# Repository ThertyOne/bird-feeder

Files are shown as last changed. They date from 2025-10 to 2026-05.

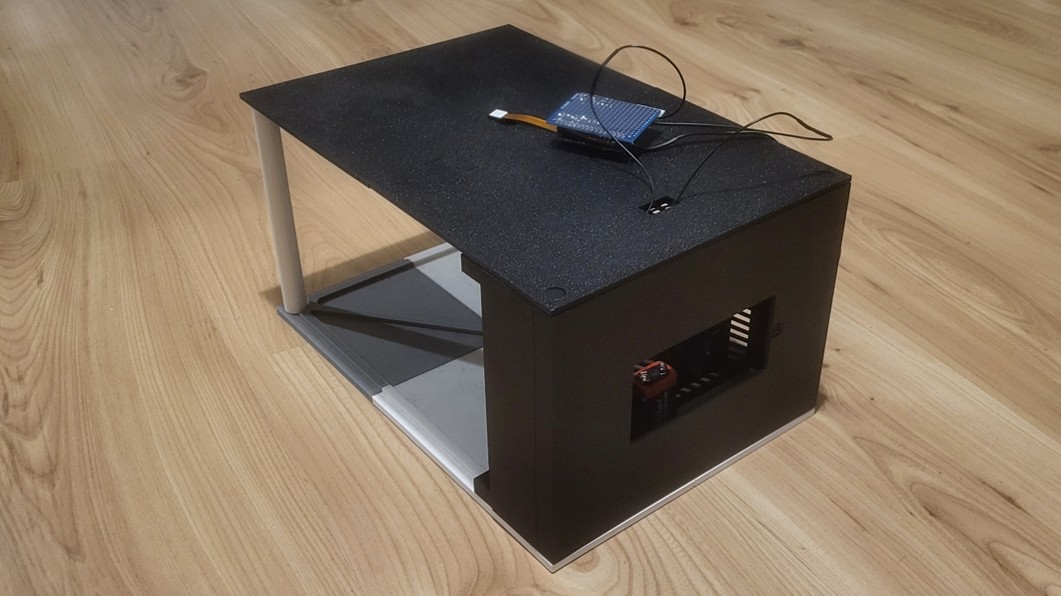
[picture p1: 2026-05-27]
SPRAWOZDANIE/Zdjęcie.jpg

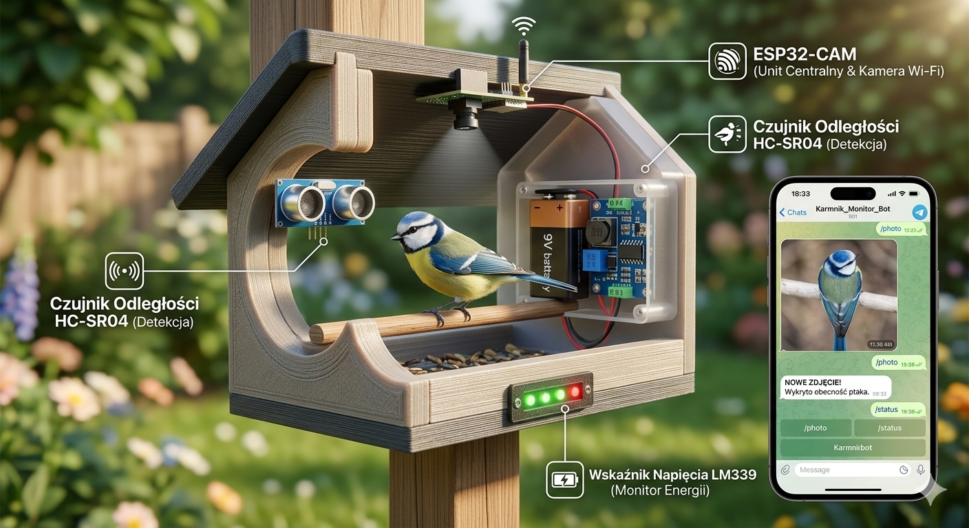
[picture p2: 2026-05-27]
SPRAWOZDANIE/wizualizacja.png

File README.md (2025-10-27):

# 🐦 Solar Bird Feeder

## 📘 Opis projektu
Projekt to **autonomiczny karmnik dla ptaków z funkcją wykonywania zdjęć**, oparty na module **ESP32-CAM**, zasilany z akumulatora **Li-Po 3,7 V / 2200 mAh**, ładowanego przez ładowarkę **TP4056** z panelem solarnym **6 V / 1 W** (możliwość połączenia 2 paneli szeregowo).  

Z wyjścia baterii energia trafia do **przetwornicy boost 5 V**, zbudowanej od podstaw na bazie generatora **PWM LMC555** i MOSFETa **IRLML6344**, która zasila ESP32 i peryferia – **serwo sterujące karmnikiem, LEDy oświetleniowe oraz czujniki**. Masa wszystkich modułów jest wspólna.  

Ładowanie z panelu odbywa się przez **diodę SS34** i **polyfuse 500 mA**, a napięcie akumulatora jest monitorowane przez dzielnik rezystorowy podłączony do ADC ESP.  

Po wykryciu ruchu przez czujnik ESP wychodzi z trybu **deep sleep**, włącza LED, wykonuje zdjęcie i wysyła je przez Wi-Fi na serwer, po czym ponownie przechodzi w uśpienie, oszczędzając energię. **Peryferia** (serwo, LEDy) są zasilane poprzez **klucz MOSFET**, który odcina zasilanie, gdy peryferia nie działają.

---

## ⚙️ Główne założenia
- Zasilanie autonomiczne: **panel solarny + akumulator Li-Po 3.7 V / 2200 mAh**
- Mikrokontroler i kamera: **ESP32-CAM (OV2640)**
- Komunikacja: **Wi-Fi**, opcjonalnie **LoRaWAN** w przyszłości
- Peryferia:
  - **Ultradźwiękowy czujnik / PIR** – detekcja obecności ptaka
  - **Serwo** – mechanizm podawania karmy
  - **Blue LED matrix 4x4** – doświetlenie sceny podczas zdjęcia
- ESP32 w trybie **deep sleep**, wybudzanie po przerwaniu z czujnika
- Przesyłanie zdjęcia i metadanych (data, godzina) do serwera lub lokalnej bazy danych

---

## ⚡ Przetwornica boost 5 V
- Źródło PWM: **LMC555 @ ~100 kHz, 3.3 V**
- MOSFET: **IRLML2502 / IRLML6344**
- Cewka: **15 μH**
- Dioda: **SS34**
- Kondensator wyjściowy: **4700 μF**
- Ograniczenie napięcia: **Zener 5 V**
- Funkcja: podnosi napięcie z 3,7 V akumulatora Li-Po do stabilnych 5 V dla ESP32 i peryferiów

---

## 🔋 Szacowane zużycie prądu
| Moduł | Tryb/obciążenie | Prąd (mA) |
|---|---|---|
| ESP32-CAM | Deep sleep | 0.1 – 0.2 |
| ESP32-CAM | Aktywne (Wi-Fi + foto) | 180 – 250 |
| Serwo | Ruch | 150 – 200 |
| LEDy | Max 4 LED | 80 – 100 |
| Czujniki | Idle | 2 – 5 |

**Średni pobór prądu:** ~10–30 mA przy większości czasu w deep sleep.  
**Maksymalny chwilowy pobór:** ~500 mA przy jednoczesnym ruchu serwa i LED.

---

## 💡 Sposoby oszczędzania energii
- ESP32 w **deep sleep**, wybudzenie tylko przy wykryciu ruchu
- Peryferia (LED, serwo) zasilane przez **MOSFET**, odcięcie zasilania gdy nieaktywne
- Minimalizacja czasu pracy Wi-Fi i kamer
- Możliwość zmniejszenia jasności LED i liczby LED w pierścieniu
- Optymalizacja częstotliwości wybudzeń w zależności od natężenia odwiedzin ptaków

---

## ☀️ Energia z baterii i paneli
- **Akumulator Li-Po:** 3,7 V / 2200 mAh → **8,14 Wh**
- **Panel solarny:** 6 V / 1 W → maksymalny prąd ładowania ~167 mA (przy pełnym słońcu)
- **2 panele szeregowo:** napięcie 12 V / prąd ~83 mA, dalej prostownik i TP4056
- **Przetwornica boost 5 V:** sprawność ~85 % → prąd pobierany z akumulatora = Iout × 5 V / (η × 3,7 V)
- **Szacowany średni pobór prądu ESP32 + peryferia:** 50 mA @ 5 V  
  I_bat ≈ (5V * 0.05A) / (0.85 * 3.7V) ≈ 79,5 mA
- **Czas pracy na baterii bez słońca:**  
  Czas pracy na baterii ≈ 2200 mAh / 79,5 mA ≈ 27,7 h ≈ 1,15 dnia
- **Chwilowe piki prądu** (serwo + LED + Wi-Fi): ~500 mA @ 5 V → Ibat_peak ≈ 800 mA  
- **Przy słonecznej pogodzie** panele mogą praktycznie utrzymać akumulator w pełnym stanie, a nawet doładować go na zapas (np. 4–5 h słońca → ~4 Wh energii)

---

## 🔧 Uwagi do przetwornicy
- Układ **boost 5 V** przy chwilowych pikach prądu (serwo + LED + Wi-Fi) mogą wystąpić spadki napięcia
- Kondensator 4700 μF pomaga w wygładzaniu napięcia przy skokach prądowych
- Zener 5 V chroni ESP32 przed przepięciem, ale warto monitorować temperaturę MOSFETa i cewki przy pełnym obciążeniu
- Ewentualne zwiększenie cewki lub dodanie małego kondensatora ceramicznego przy MOSFET zwiększy stabilność przy dużym poborze

---

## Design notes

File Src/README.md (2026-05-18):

# Intelligent Bird Feeder ESP32-CAM

Oprogramowanie do projektu inteligentnego karmnika dla ptaków oparty o moduł ESP32-CAM.  
System łączy się z siecią Wi-Fi, komunikuje się z botem Telegrama i docelowo ma wykonywać zdjęcia oraz rozpoznany gatunek, po wykryciu obecności ptaka.

## Funkcjonalności

Aktualnie zaimplementowane:

- konfiguracja projektu przez osobny plik `config.h`,
- połączenie ESP32-CAM z siecią Wi-Fi,
- inicjalizacja kamery OV2640,
- wykonywanie zdjęcia,
- wysyłanie zdjęcia przez Telegram,
- podstawowa struktura modułowa kodu,
- detekcja ptaka z użyciem czujnika ruchu / odległości,
- obsługa komend Telegrama,
- przygotowany moduł komunikacji z Telegram Bot API.

Planowane / rozwijane:

- rozpoznawanie gatunku ptaka.

## Struktura projektu

```txt
src/
├── main.cpp
├── config.h                    # lokalny plik konfiguracyjny, nie obecny w repo
├── config.example.h            # przykładowa konfiguracja  
|     
├── sensors_n_actuators/        # moduły fizyczne
│     ├── camera/
│     |     ├── camera.h
│     |     └── camer.cpp
|     |
│     ├── pir_sensor/
│     |     ├── pir_sensor.h
│     |     └── pir_sensor.cpp
|     |
│     ├── wifi_meneger/
│           ├── wifi_meneger.h
│           └── wifi_meneger.cpp
|
└── telegram/                   # serwer Telegram
      ├── telegram.h
      └── telegram.cpp
```

## Konfiguracja
Utwórz plik `src/config.h` na podstawie `src/config.example.h`:
```c
#define SSID_1 "NAZWA_WIFI"
#define PASSWORD_1 "HASLO_WIFI"

#define BOT_TOKEN "TOKEN_BOTA_TELEGRAM"
#define CHAT_ID "ID_CZATU"

#define PIR_SENSOR_PIN 14
#define FLASH_LED_PIN 4
#define SERVO_PIN 15
```

## Uruchomienie debugowania
1. Skonfiguruj `config.h`.
2. Podłącz `ESP32-CAM` do stabilnego zasilania 5 V.
3. Wgraj program na płytkę.
4. Otwórz Serial Monitor z prędkością: `115200 baud`.
5. Sprawdź, czy urządzenie poprawnie łączy się z Wi-Fi.

## Docs
### Telegram:
Moduł `TelegramManager` odpowiada za komunikację ESP32-CAM z Telegram Bot API.

Obsługuje:
- wysyłanie wiadomości tekstowych,
- wysyłanie zdjęć JPEG,
- odbieranie prostych komend użytkownika.

## Wymagania konfiguracyjne

W pliku `config.h` muszą być zdefiniowane:

```cpp
#define BOT_TOKEN "telegram_bot_token"
#define CHAT_ID "authorized_chat_id"
#define BOT_REQUEST_DELAY 1000UL

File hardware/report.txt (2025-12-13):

Plotted to 'C:\Users\mrvan\OneDrive\Pulpit\plytka do roboty\hardware-B_Cu.gbr'.
Created Gerber job file 'C:\Users\mrvan\OneDrive\Pulpit\plytka do roboty\hardware-job.gbrjob'.
Informacja: Done.
Informacja: Done.

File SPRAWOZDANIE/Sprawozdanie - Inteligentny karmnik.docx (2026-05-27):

# Sprawozdanie projektowe

Inteligentny karmnik

Autorzy:

Dominik Bukowicz Jan Mikołajczyk Wojciech Odziomek Wojciech Kośnik-Kowalczuk | 268519 268563 264259 245728

# Cel pracy

Głównym celem projektu było zaprojektowanie i wykonanie autonomicznego systemu monitoringu ptaków, zintegrowanego z karmnikiem wykonanym w technologii druku 3D. Urządzenie ma za zadanie wykrywać obecność ptaków wewnątrz karmnika, wykonywać zdjęcie i przesyłać je w czasie rzeczywistym do użytkownika za pośrednictwem komunikatora Telegram.

# Założenia projektowe

Projekt opiera się na następujących założeniach technicznych:

- Jednostka centralna: Moduł ESP32-CAM z wbudowaną kamerą i łącznością Wi-Fi.
- Detekcja: Ultradźwiękowy czujnik odległości HC-SR04 wykrywający obiekt w zasięgu 2–200 cm.
- Zasilanie: Bateria 9V, obniżana do stabilnego poziomu 5V za pomocą przetwornicy impulsowej.
- Monitoring energii: Analogowy wskaźnik napięcia na komparatorze LM339, sygnalizujący poziom rozładowania baterii za pomocą 4 diod LED.
- Komunikacja: Telegram Bot API (interakcja przez Father Bot).
- Obudowa: Konstrukcja modułowa zaprojektowana do druku 3D.

# Uzasadnienie doboru elementów

Wybór komponentów podyktowany był optymalizacją kosztów oraz energooszczędnością:

- ESP32-CAM: Wybrany ze względu na zintegrowany moduł Wi-Fi oraz niską cenę w stosunku do możliwości przetwarzania obrazu.
- HC-SR04: Czujnik ten pozwala na precyzyjne określenie momentu pojawienia się ptaka przy ziarnie, co minimalizuje liczbę "pustych" zdjęć, w przypadku gdyby były one robione z określoną częstotliwością.
- Przetwornica LM2592 (Step-down): Zastosowanie przetwornicy impulsowej zamiast stabilizatora liniowego (np. 7805) pozwala na uzyskanie znacznie wyższej sprawności, co jest kluczowe przy zasilaniu bateryjnym.
- LM339: Poczwórny komparator napięcia pozwala na realizację czytelnego, 4-stopniowego wskaźnika poziomu energii przy minimalnej liczbie komponentów zewnętrznych.

# Symulacja układu elektronicznego w LtSpice

Przed przystąpieniem do projektowania płytki PCB, układ wskaźnika napięcia został poddany symulacji w programie LTSpice.

Analiza teoretyczna: Układ działa jako dzielnik napięcia porównujący napięcie baterii z napięciem odniesienia (5V z przetwornicy). Próg załączenia diody LED określa wzór:

V_(th) = V_(ref) (1+ (R_(pot_h) / R_(pot_l) ))

gdzie:

Vref - stałe napięcie 5V, a stosunek rezystancji potencjometru określa punkt krytyczny dla baterii 9V.

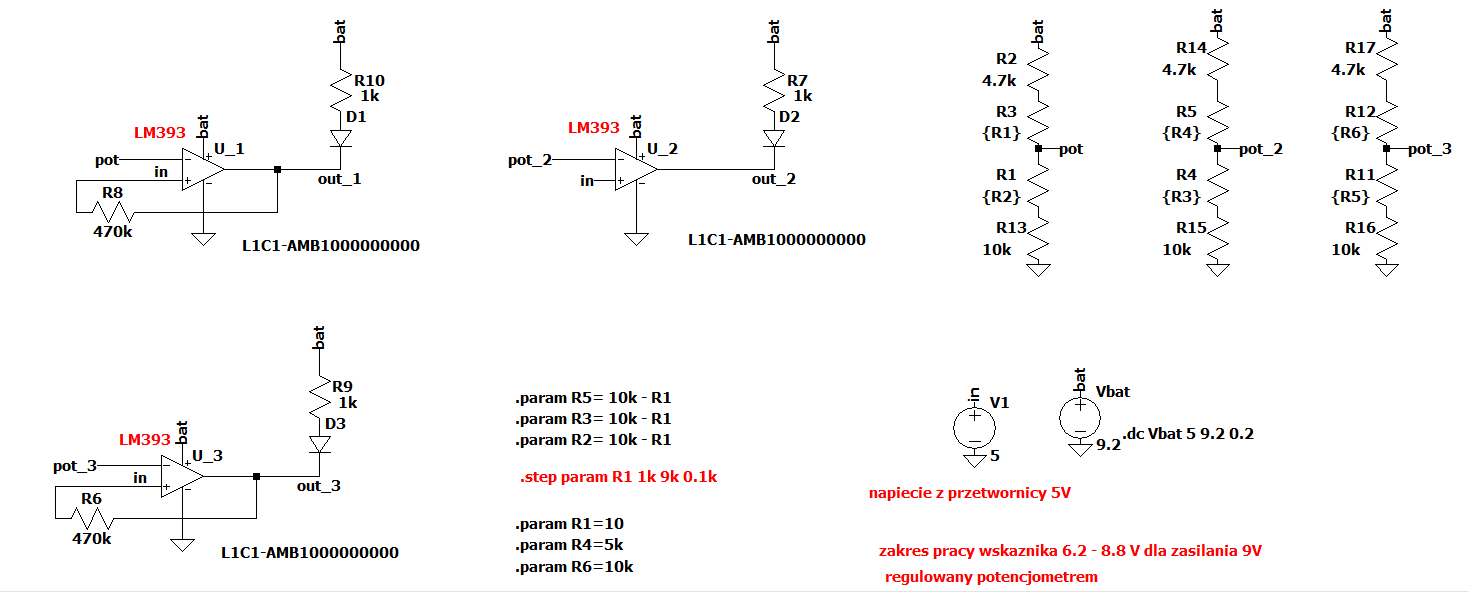
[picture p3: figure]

Rys. 1 Symulowany schemat

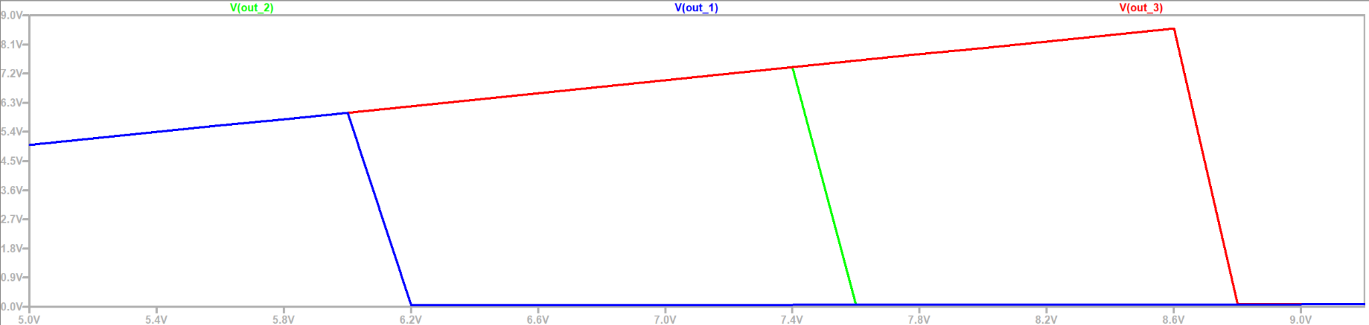
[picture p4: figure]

Rys. 2 Wynik symulacji

Symulacja wykazała, że układ poprawnie reaguje na spadek napięcia w zakresie od 8,8 V do około 6,2V, co odpowiada bezpiecznemu zakresowi pracy baterii alkalicznej.

# Projekt płytki obwodów drukowanych w KiCAD

Projekt PCB został zrealizowany w środowisku KiCAD. Zdecydowano się na płytkę jednostronną, co ułatwia jej wykonanie metodą termotransferu dostępnej w ramach laboratorium.

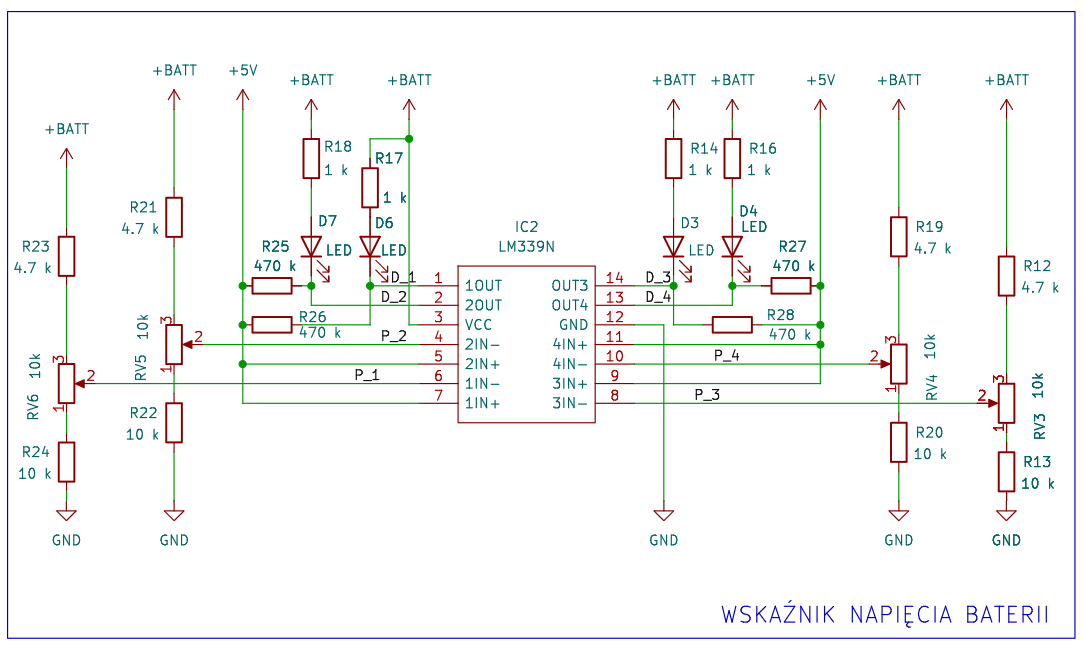
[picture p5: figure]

Rys. 3 Schemat elektryczny zaprojektowanego wskaźnika napięć

Cechy projektu PCB:

- Zasilanie: Płytka posiada dwa odseparowane wejścia: dla baterii 9V oraz dla napięcia 5V z modułu zewnętrznej przetwornicy.
- Prowadzenie ścieżek: Ze względu na ograniczenia jednej warstwy, zastosowano jedną "zworkę" (przelotkę przewlekany) dla szyny zasilania 5V.
- Kalibracja: Na płytce umieszczono cztery potencjometry montażowe (RV3-RV6), które pozwalają na precyzyjne ustawienie progów dla każdej z diod LED.

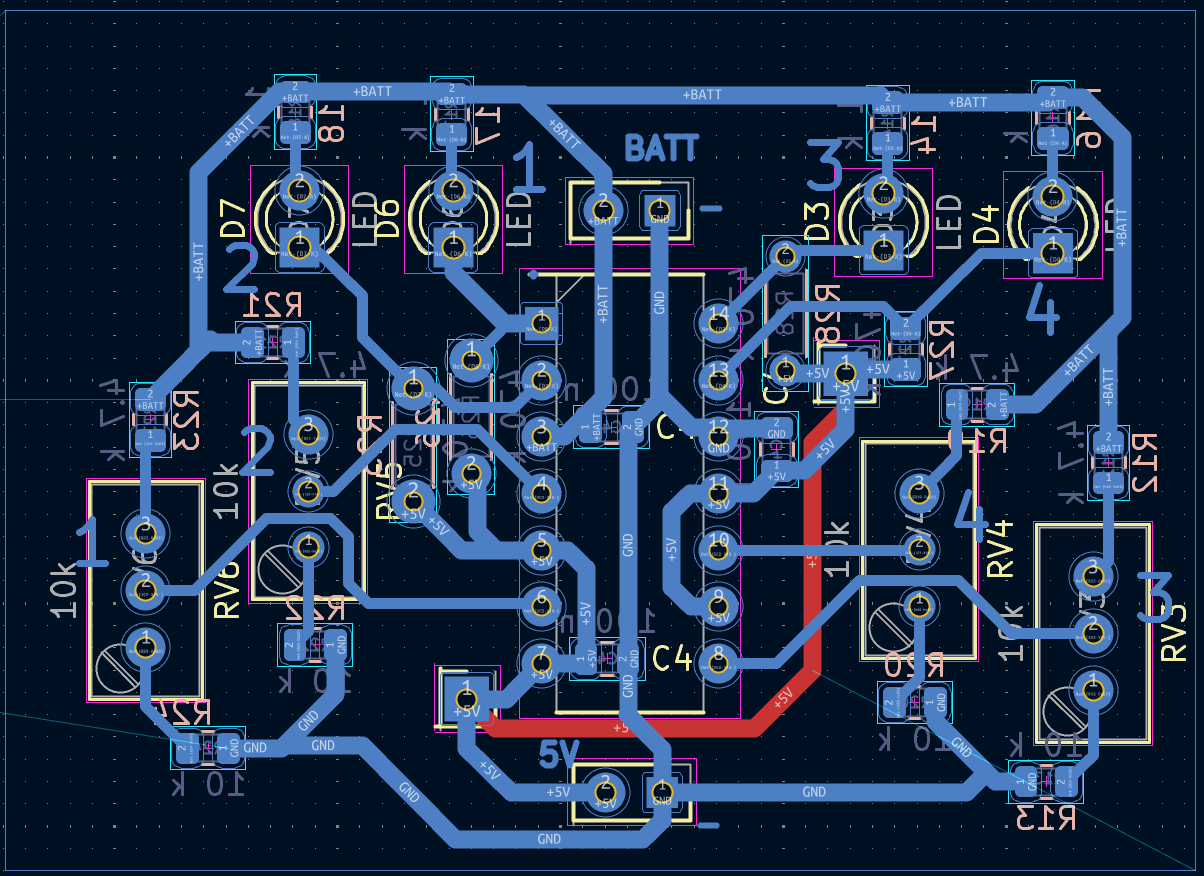
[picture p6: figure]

Rys. 4 Widok płytki jednostronnej

# Testy zaprojektowanego układu elektronicznego

Proces testowania skupił się na kalibracji wskaźnika napięcia oraz weryfikacji logiki ESP32-CAM.

1. Kalibracja wskaźnika: Do wejścia baterii podłączono zasilacz laboratoryjny. Zmieniając napięcie od 9.5V w dół, regulowano potencjometry tak, aby diody gasły kolejno przy poziomach: 8.5V, 7.8V, 7.0V oraz 6.5V. W celu uzyskania napięcia odniesienia Uref na czas testów wykorzystano pin 5V z ESP32.
2. Weryfikacja zasilania: Przetwornica LM2592 utrzymywała stabilne 5.02V przy obciążeniu modułem ESP32 podczas transmisji danych, co potwierdziło poprawność doboru układu zasilania.

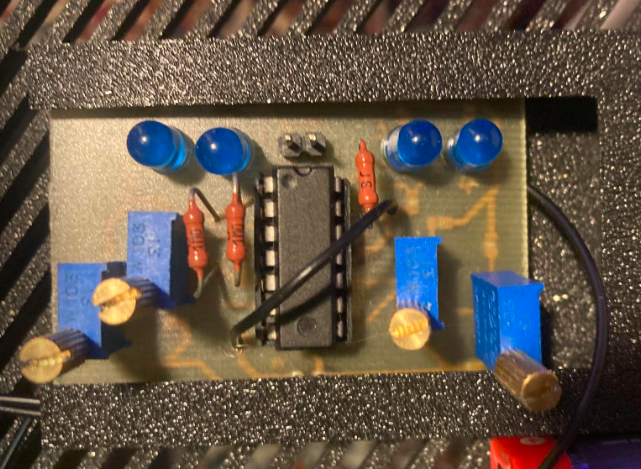
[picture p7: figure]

Rys. 5 Fotografia przedstawiająca zrealizowany układ elektroniczny

# Oprogramowanie

Oprogramowanie sterujące zostało przygotowane dla modułu ESP32-CAM i odpowiada za inicjalizację urządzenia, komunikację sieciową, obsługę kamery, odbiór komend użytkownika oraz reakcję na sygnał z czujnika obecności. Zgodnie z założeniami projektu urządzenie ma wykrywać obecność ptaka w karmniku, wykonywać zdjęcie i przesyłać je użytkownikowi przez komunikator Telegram. W projekcie zastosowano moduł ESP32-CAM z kamerą i łącznością Wi-Fi, komunikację przez Telegram Bot API oraz zasilanie 5 V uzyskane z przetwornicy obniżającej napięcie baterii.

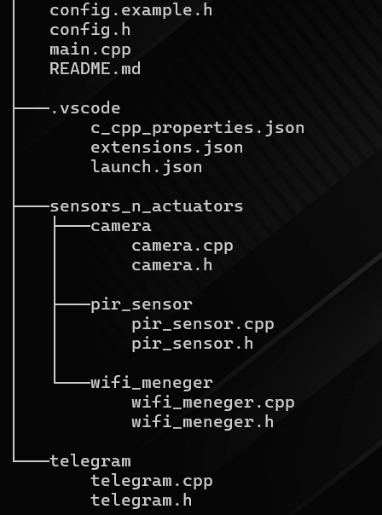
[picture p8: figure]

Program został podzielony na kilka modułów funkcjonalnych. Plik konfiguracyjny przechowuje parametry sieci Wi-Fi, token bota Telegram, identyfikator czatu oraz ustawienia pinów i czasów pracy czujnika. Moduł Wi-Fi odpowiada za połączenie urządzenia z siecią bezprzewodową. Moduł kamery inicjalizuje sensor OV2640, konfiguruje rozdzielczość obrazu oraz udostępnia funkcje wykonania i zwolnienia zdjęcia. Moduł Telegram obsługuje wysyłanie wiadomości tekstowych, wysyłanie zdjęć oraz odbiór komend użytkownika. Moduł czujnika PIR odpowiada za odczyt stanu wejścia cyfrowego, filtrację drgań sygnału oraz ograniczenie częstotliwości kolejnych wyzwoleń.

Po uruchomieniu program wykonuje sekwencję inicjalizacji. Najpierw uruchamiany jest port szeregowy oraz ładowane są parametry konfiguracyjne. Następnie ESP32-CAM łączy się z siecią Wi-Fi. Po poprawnym połączeniu inicjalizowany jest bot Telegram, kamera oraz czujnik PIR. Jeżeli któryś z krytycznych modułów nie zostanie poprawnie uruchomiony, system przechodzi w stan ograniczonej pracy lub sygnalizuje błąd diagnostyczny.

Główna pętla programu działa w oparciu o prostą maszynę stanów. W trybie bezczynności urządzenie nie wykonuje automatycznie zdjęć i oczekuje na komendy przesyłane przez Telegram. Komendy pozwalają m.in. uruchomić tryb cichy, tryb diagnostyczny, zatrzymać automatyczne działanie lub wykonać test wybranego modułu. W trybie cichym system cyklicznie sprawdza stan czujnika PIR. Po wykryciu ruchu wykonywane jest zdjęcie, a następnie obraz wraz z krótką informacją jest wysyłany do użytkownika przez Telegram. Po wykonaniu zdjęcia aktywowany jest czas blokady, który zapobiega wielokrotnemu reagowaniu na ten sam obiekt.

Wysyłanie zdjęcia realizowane jest przez ręczne żądanie HTTPS POST do Telegram Bot API. Obraz pobrany z kamery ma postać bufora JPEG, który jest przesyłany jako formularz multipart/form-data. Po zakończeniu transmisji bufor zdjęcia jest zwracany do sterownika kamery, co zapobiega zablokowaniu pamięci i umożliwia wykonywanie kolejnych zdjęć.

W celu ułatwienia uruchamiania systemu przewidziano również tryby diagnostyczne. Użytkownik może sprawdzić podstawowy stan Wi-Fi, kamery i czujnika obecności oraz uruchomić test czujnika PIR. Diagnostyka była szczególnie istotna podczas integracji, ponieważ komunikacja Telegram jest asynchroniczna i może wprowadzać opóźnienia między zdarzeniem w urządzeniu a odebraniem wiadomości przez użytkownika. Dodatkowo zaimplementowano logowanie wiadomości debugu poprzez interfejs UART i HTTP.

Przykład logowania informacji poprzez interfejs UART:

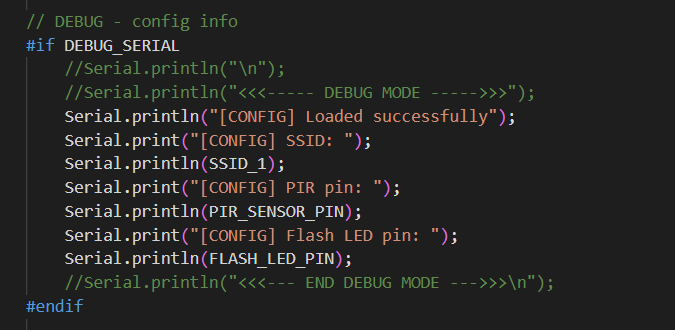
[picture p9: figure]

Przykład funkcji testującej wywoływanej przez użytkownika poprzez zapytanie wysłane telegramem:

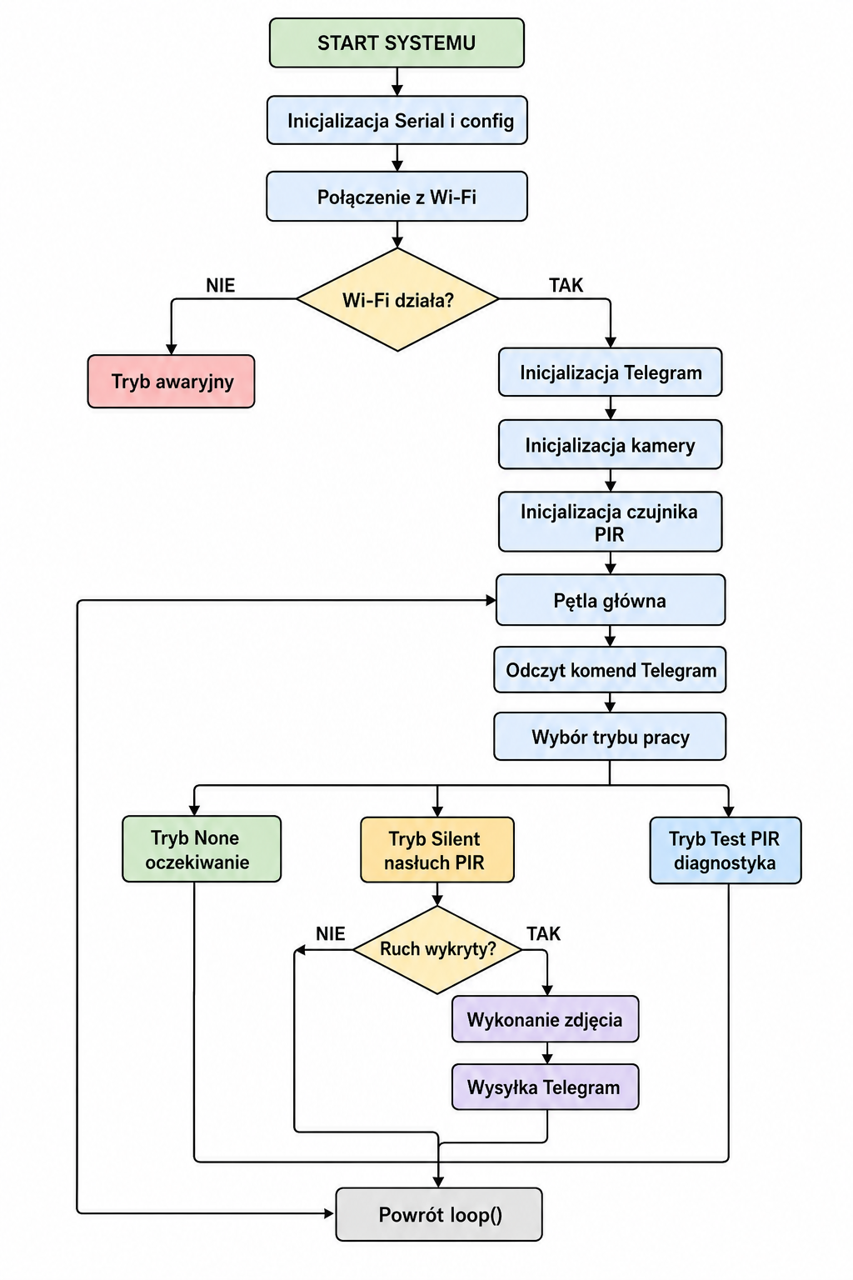
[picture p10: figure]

## Schemat blokowy działania programu sterującego

## Interfejs użytkownika – Telegram messages

Przykłady wiadomości wysyłanych przez urządzenie via telegram:

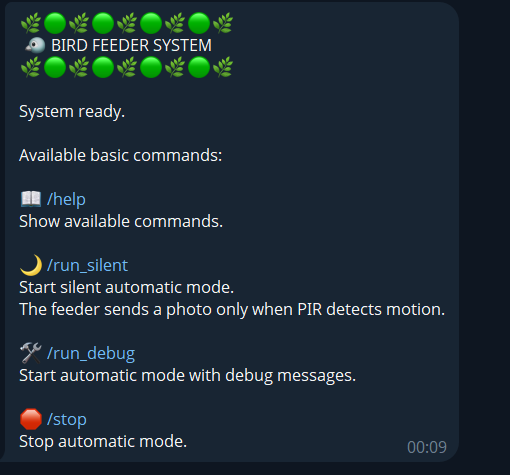
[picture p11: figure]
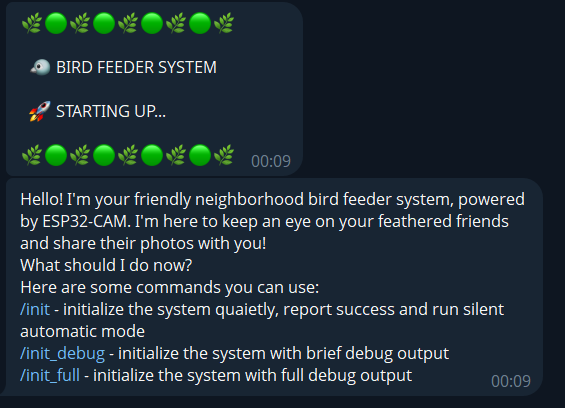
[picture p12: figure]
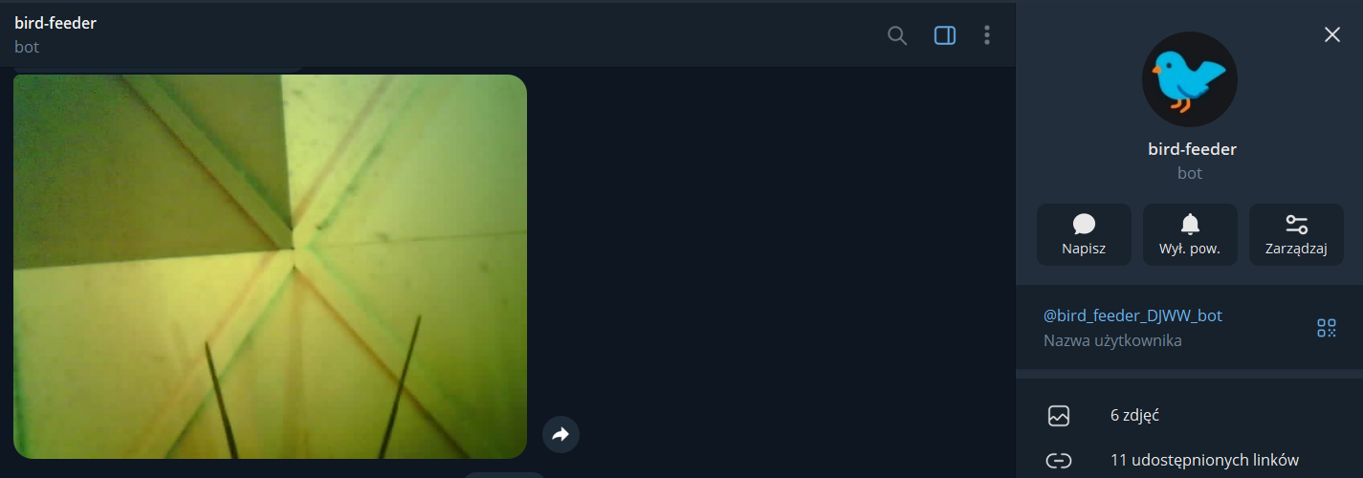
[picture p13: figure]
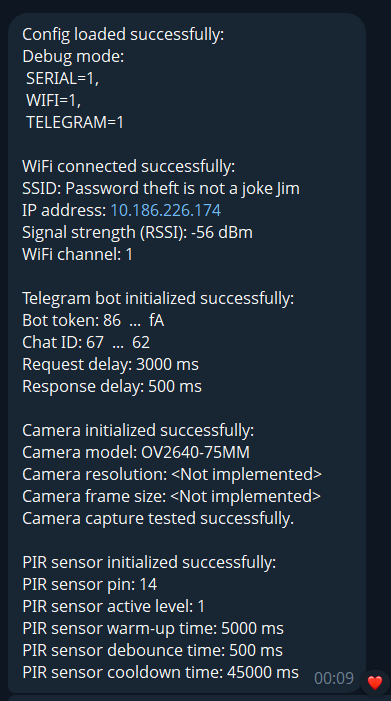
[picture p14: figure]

# Projekt obudowy opracowanego urządzenia

Obudowa karmnika została zaprojektowana w programie Autodesk Inventor jako konstrukcja w pełni modułowa, złożona z kilkunastu osobnych elementów. Podejście modułowe podyktowane było ograniczeniami obszaru roboczego dostępnych drukarek FDM — żaden z elementów nie przekracza gabarytów 150 × 300 mm w rzucie poziomym.

## Dobór technologii wytwarzania

W początkowej fazie projektu rozważano wykonanie obudowy metodą stereolitografii (SLA). Rozwiązanie to zostało jednak odrzucone z dwóch zasadniczych powodów. Po pierwsze, gabaryty poszczególnych elementów przekraczały obszar roboczy dostępnego drukarki SLA. Po drugie, żywica fotopolimerowa wykazuje niekorzystne właściwości użytkowe w warunkach zewnętrznych — pod wpływem promieniowania UV ulega dalszemu utwardzaniu, co z czasem prowadzi do kruchości i pękania materiału. Istotnym argumentem był również aspekt biologiczny: żywice epoksydowe stosowane w druku SLA nie są obojętne dla środowiska i organizmów żywych, co w przypadku urządzenia mającego bezpośredni kontakt z ptakami stanowiło niedopuszczalne ryzyko.

Z powyższych względów zdecydowano się na technologię FDM z filamentem PLA — materiałem biodegradowalnym, stabilnym mechanicznie i powszechnie uznawanym za bezpieczny biologicznie.

## Struktura obudowy

- Podstawa — złożona z czterech segmentów (podstawa_cz1 ÷ podstawa_cz4), każdy o wymiarach około 125–175 × 100 × 8 mm. Podział na cztery części umożliwił wydruk bez konieczności stosowania podpór oraz zapewnił stabilność całej konstrukcji po złożeniu.
- Ściana tylna (tył_off) — element o wymiarach około 300 × 155 × 34 mm, stanowiący zamknięcie komory elektronicznej od tyłu, z przestrzenią na prowadzenie okablowania.
- Sufit — podzielony na trzy elementy (sufit, sufit_1, sufit_2) o łącznej rozpiętości 300 mm i głębokości 200 mm, tworzące zadaszenie karmnika chroniące elektronikę i pokarm przed opadami.
- Drzwiczki — panel frontowy o wymiarach 50 × 115,5 × 4,8 mm, umożliwiający dostęp serwisowy do wnętrza urządzenia (wymiana baterii, rekalibracja układu).
- Kolumna (kolumna_off) — element dystansowy o wymiarach 15 × 155 × 14,8 mm, utrzymujący właściwą odległość między podsystemami.
- Uchwyt płytki PCB (uchwyt_płytki) — dedykowany element mocujący, zapewniający stabilne i powtarzalne pozycjonowanie płytki wskaźnika napięcia wewnątrz obudowy.
- Uchwyt drzwi (uchwyt_drzwi) — niewielki element zawiasowy o wymiarach 44 × 3 × 2 mm, umożliwiający uchylne otwieranie panelu frontowego.

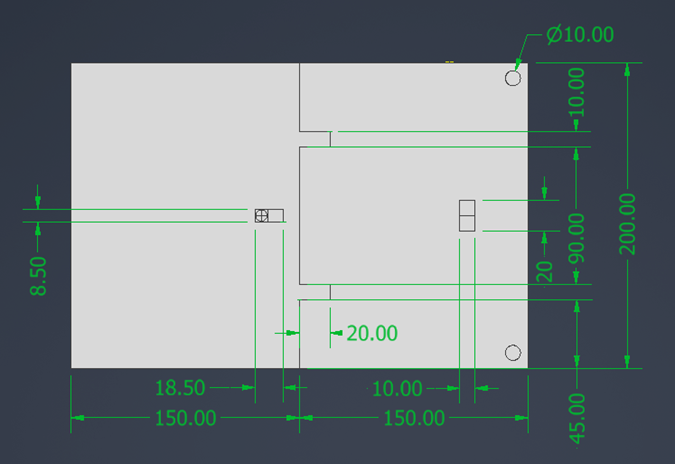
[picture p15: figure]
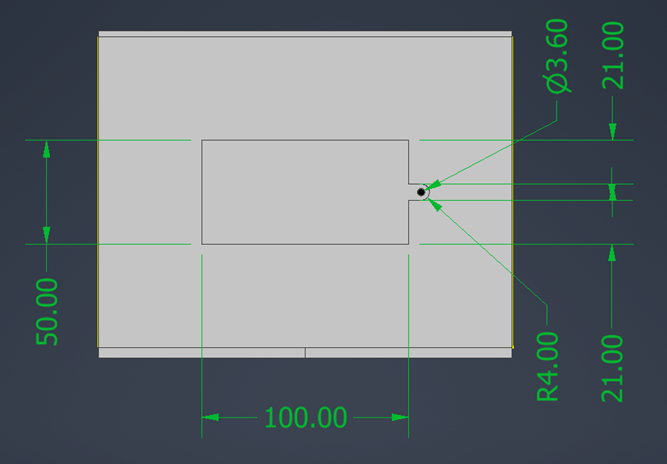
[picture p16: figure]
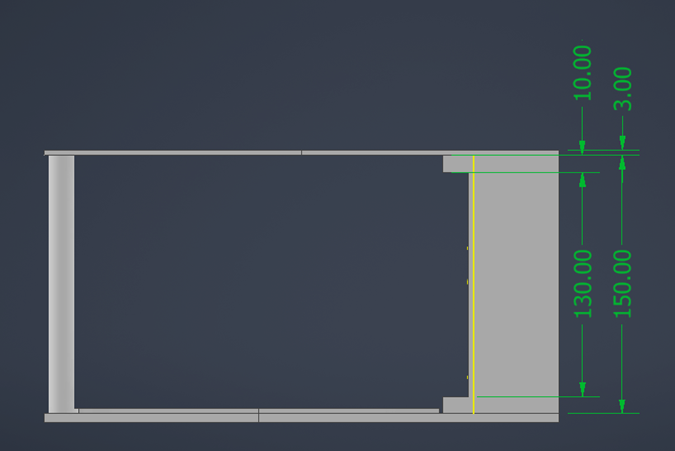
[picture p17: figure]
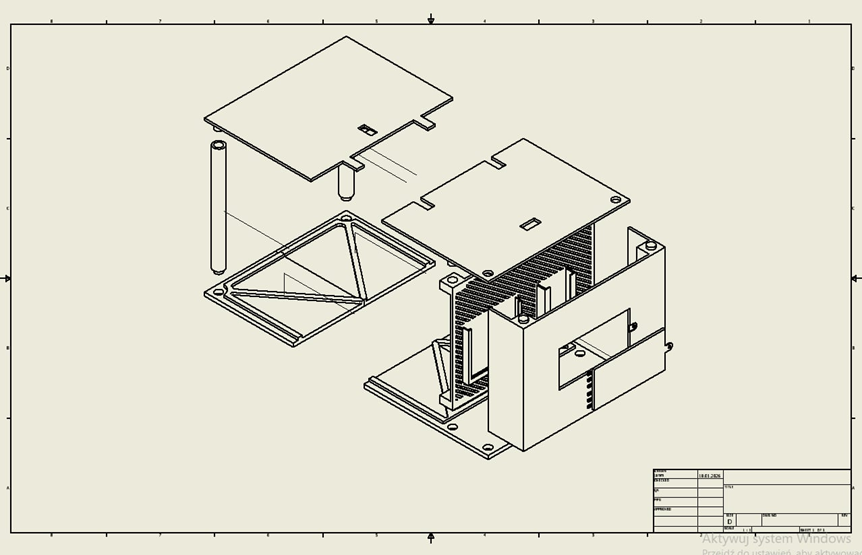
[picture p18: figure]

## Parametry druku

Wszystkie elementy zostały wydrukowane z filamentu PLA przy użyciu drukarki Bambu Lab X1E z dyszą 0,4 mm, w oprogramowaniu Bambu Studio z domyślnym profilem dla PLA. Zastosowane parametry to: grubość warstwy 0,2 mm (pierwsza warstwa 0,2 mm), wypełnienie gyroid o gęstości 20%, prędkość druku w trybie Standard (zewnętrzne ścianki ~100 mm/s, wypełnienie ~200 mm/s). Temperatura druku wynosiła 220°C dla dyszy i 35°C dla podgrzewanego stołu z płytą PEI.

## Złożenie obudowy

Elementy łączone są ze sobą za pomocą pasowania wciskowego i kleju. Modułowa budowa umożliwia demontaż dowolnego segmentu bez rozkładania całego urządzenia, co znacząco ułatwia konserwację i ewentualną wymianę podzespołów elektronicznych. Z uwagi na fakt, że jest to prototyp urządzenia, istnieje możliwość łatwej zmiany jednego z elementów na taki o innych wymiarach, odpowiadający kolejnym iteracjom płytek PCB, zastosowanej kamery, czujników.

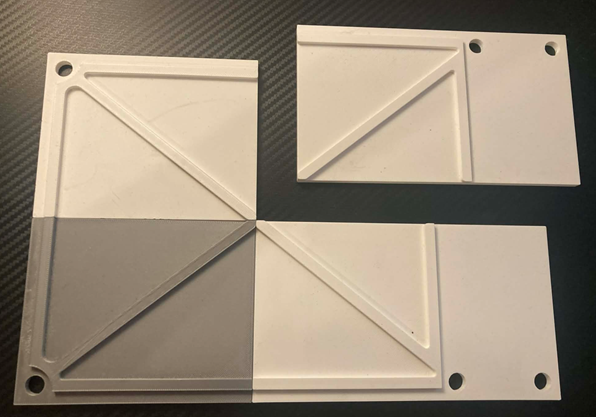
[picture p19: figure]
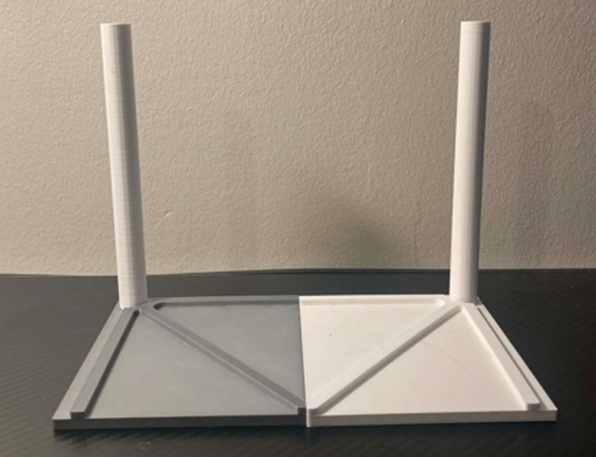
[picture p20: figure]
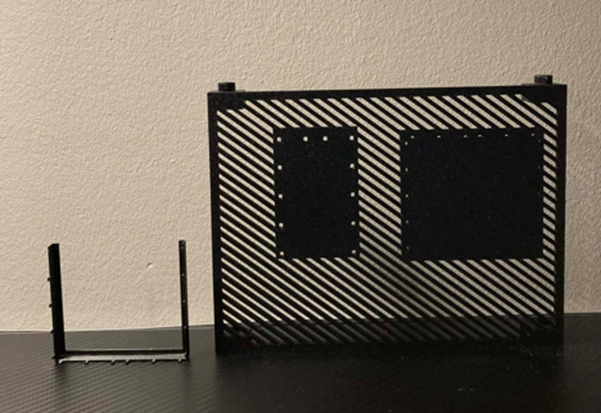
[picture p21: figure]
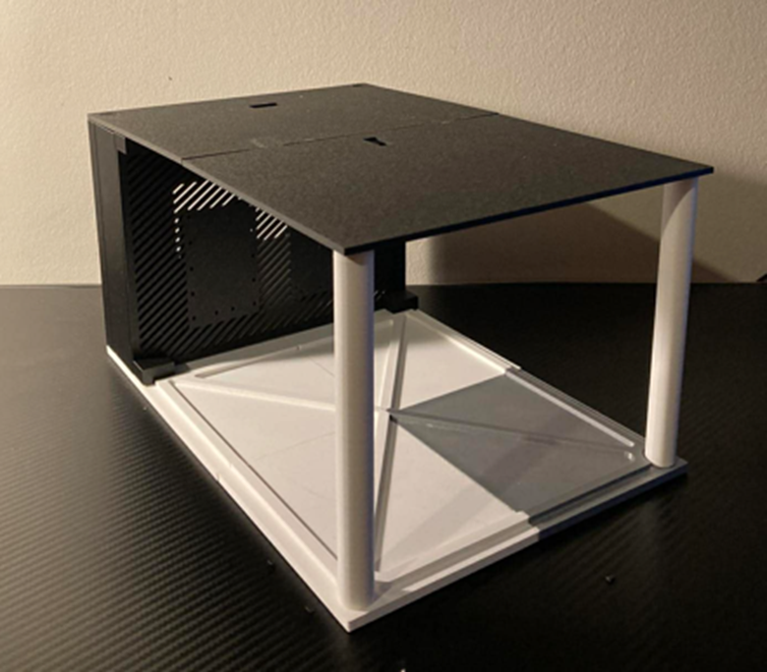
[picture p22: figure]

Laboratorium Otwarte

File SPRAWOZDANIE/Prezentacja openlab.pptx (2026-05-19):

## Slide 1

Dominik Bukowicz 268519
Jan Mikołajczyk 268563
Wojciech Odziomek 264259
Wojciech Kośnik-Kowalczuk 245728

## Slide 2

Cel projektu - inteligentny karmnik

Głównym celem projektu było zaprojektowanie i wykonanie autonomicznego systemu monitoringu ptaków, zintegrowanego z karmnikiem wykonanym w technologii druku 3D. Urządzenie ma za zadanie wykrywać obecność ptaków wewnątrz karmnika, wykonywać zdjęcie i przesyłać je w czasie rzeczywistym do użytkownika za pośrednictwem komunikatora Telegram.

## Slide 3

Założenia projektowe

- Jednostka centralna: Moduł ESP32-CAM z wbudowaną kamerą i łącznością Wi-Fi.
- Detekcja: Ultradźwiękowy czujnik odległości HC-SR04 wykrywający obiekt w zasięgu 2–200 cm.
- Zasilanie: Bateria 9V, obniżana do stabilnego poziomu 5V za pomocą przetwornicy impulsowej.
- Monitoring energii: Analogowy wskaźnik napięcia na komparatorze LM339, sygnalizujący poziom rozładowania baterii za pomocą 4 diod LED.
- Komunikacja: Telegram Bot API (interakcja przez Father Bot).
- Obudowa: Konstrukcja modułowa zaprojektowana do druku 3D.

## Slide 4

Uzasadnienie doboru elementów

- ESP32-CAM: Wybrany ze względu na zintegrowany moduł Wi-Fi oraz niską cenę w stosunku do możliwości przetwarzania obrazu.
- HC-SR04: Czujnik ten pozwala na precyzyjne określenie momentu pojawienia się ptaka przy ziarnie, co minimalizuje liczbę "pustych" zdjęć, w przypadku gdyby były one robione z określoną częstotliwością.
- Przetwornica LM2592 (Step-down): Zastosowanie przetwornicy impulsowej zamiast stabilizatora liniowego (np. 7805) pozwala na uzyskanie znacznie wyższej sprawności, co jest kluczowe przy zasilaniu bateryjnym.
- LM339: Poczwórny komparator napięcia pozwala na realizację czytelnego, 4-stopniowego wskaźnika poziomu energii przy minimalnej liczbie komponentów zewnętrznych.

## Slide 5

Uzasadnienie doboru elementów

Analiza teoretyczna: Układ działa jako dzielnik napięcia porównujący napięcie baterii z napięciem odniesienia (5V z przetwornicy). Próg załączenia diody LED określa wzór:
Vth = Vref (1+ (Rpot_h / Rpot_l))
gdzie:
Vref - stałe napięcie 5V, a stosunek rezystancji potencjometru określa punkt krytyczny dla baterii 9V.

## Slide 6

Symulacja działania układu elektronicznego

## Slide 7


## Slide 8

Projekt płytki PCB


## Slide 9

Testy zaprojektowanego układu

1. Kalibracja wskaźnika: Do wejścia baterii podłączono zasilacz laboratoryjny. Zmieniając napięcie od 9.5V w dół, regulowano potencjometry tak, aby diody gasły kolejno przy poziomach: 8.5V, 7.8V, 7.0V oraz 6.5V. W celu uzyskania napięcia odniesienia Uref na czas testów wykorzystano pin 5V z ESP32.
2. Weryfikacja zasilania: Przetwornica LM2592 utrzymywała stabilne 5.02V przy obciążeniu modułem ESP32 podczas transmisji danych, co potwierdziło poprawność doboru układu zasilania.


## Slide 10

Oprogramowanie sterujące
Schemat blokowy


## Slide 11

Komunikacja z aplikacją Telegram


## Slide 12

Projekt obudowy karmnika

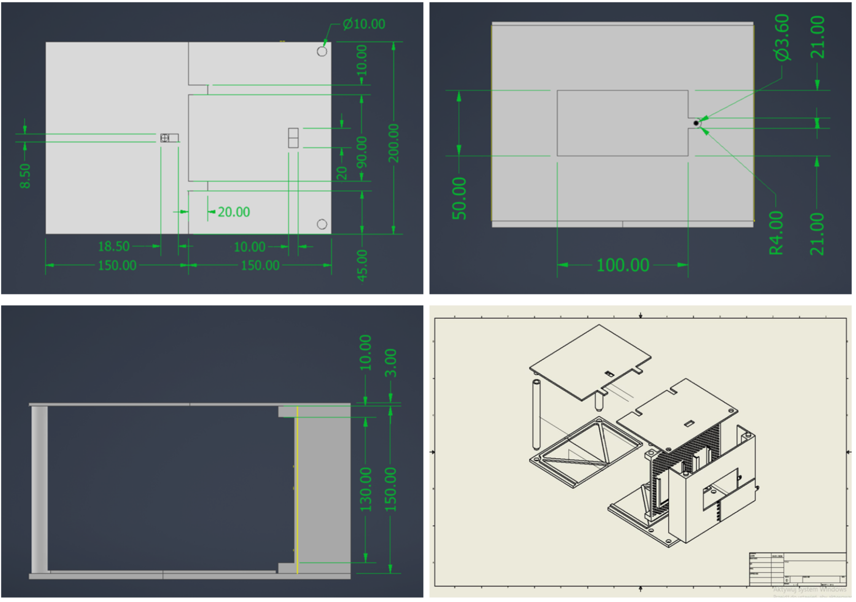
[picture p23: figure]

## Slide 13

Efekt końcowy

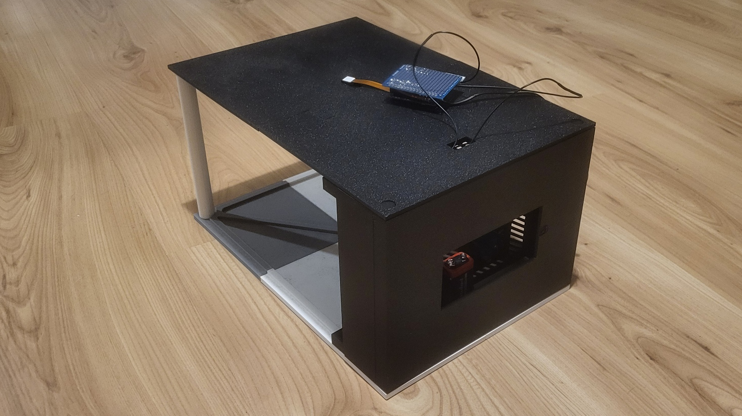
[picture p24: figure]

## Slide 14

Dziękujemy za uwagę

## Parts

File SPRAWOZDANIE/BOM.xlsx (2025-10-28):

Item | Discription |  | Price [zł] | Link | is in KiCAD?
Headers 2.54 mm female x8 |  | 2 | 3.46 | https://www.tme.eu/pl/details/zl262-8sg/listwy-i-gniazda-kolkowe/connfly/ds1023-1-8s21/ | y
Headers 2.54 mm female x2 |  | 1
Headers 2.54 mm female x3 | caounts as famale x4 below | 2
Headers 2.54 mm female x4 |  | 1 | 2.84 | https://www.tme.eu/pl/details/zl262-4sg/listwy-i-gniazda-kolkowe/connfly/ds1023-1-4s21/ | y
Złącze ARK raster 2,54 mm 2 |  | 3 | 11.5 | https://botland.com.pl/zlacza-ark/9443-zlacze-ark-raster-254mm-2-pin-10szt-5904422313340.html
TP4056 Li-Po charger module |  | 1 | 6.3 | https://botland.com.pl/moduly-ladowania-lipol-usb-micro-usb/6944-ladowarka-li-pol-tp4056-pojedyncza-cela-1s-37v-microusb-z-zabezpieczeniami-5904422375355.html | y
Akumulator Li-Po 1S 2200 mAh (Akyga AKU-06034) |  | 1 | 31.9 | https://botland.com.pl/akumulatory-li-pol-1s-37v/6034-akumulator-li-pol-akyga-2200mah-1s-37v-przewody-50mm-59x37x9mm-5904422334277.html
Panel solarny 6 V / 1 W (136×110 mm) |  | 1 | 34.9 | https://botland.com.pl/panele-sloneczne-malej-mocy/3694-ogniwo-sloneczne-1w6v-136x110x3mm-5904422302870.html
 | 3.3 V stabilization | 1
 |  |  |  |  | y
Dioda Schottky SS34 | Blocking back current | 2 | 2.3 | https://www.tme.eu/pl/details/ss34-ons/diody-schottky-smd/onsemi/ss34/ | y
Polyfuse PPTC 500 mA | Ptotection of charging panel | 1 | 0.73 | https://www.tme.eu/pl/details/0zcf0050ff2c/bezpieczniki-polimerowe-smd/bel-fuse/ | y
Inductor | Inductor 15 µH | 1
 | C_out 4700 µF 6.3 V low-ESR (electrolytic/tantal) for 5V output | 1 |  | https://www.tme.eu/pl/details/eeufc0j222/kondensatory-elektrolityczne-tht/panasonic/ | y
 | C_out 2200 µF 6.3 V low-ESR (backup) | 1 |  | https://www.tme.eu/pl/details/eeufc0j222/kondensatory-elektrolityczne-tht/panasonic/ | y
 | C_in 470 µF 6.3 V low-ESR | 1 |  | https://www.tme.eu/pl/details/eeufc0j471/kondensatory-elektrolityczne-tht/panasonic/ | y
n-MOSFET | IRLML2502TRPBF | 3 |  | https://www.tme.eu/pl/details/irlml2502trpbf/tranzystory-z-kanalem-n-smd/infineon-technologies/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 | y
PWM gen | NE555 | 1 | 1.1 | https://botland.com.pl/uklady-scalone-czasowe/187-uniwersalny-uklad-czasowy-ne555-tht-5904422355432.html | y
 | 1N5818 | 1 | 1 | https://www.tme.eu/pl/details/1n5818-dio/diody-schottky-tht/diotec-semiconductor/1n5818/ | y
 | Resistors 10k | 2
 | Resistors 100k | 2
 | Resistor 330 Ohm for LED | 3 |  |  | y
 | LED SMD | 3 | 0.15 | https://www.tme.eu/pl/details/ls-r976/diody-led-smd-kolorowe/ams-osram/ls-r976/ | y
 | Gate resistor 100 Ohm | 2
 | Gate resistor 100k Ohm | 2
WS2812 7-LED ring | LED ring | 1
 | Micro servo | 1
 | Series data resistor 330 Ω (0603) for WS2812 | 1
 | Ultrasonic sensor HC-SR04 | 1

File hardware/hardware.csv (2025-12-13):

Reference | Qty | Value | DNP | Exclude from BOM | Exclude from Board | Footprint | Datasheet
C1,C2,C9,C12 | 4 | 1 n |  |  |  | Capacitor_SMD:C_0603_1608Metric | ~
C3,C4 | 2 | 10 μ |  |  |  | Capacitor_SMD:C_0603_1608Metric | ~
C5,C6 | 2 | 100 μ |  |  |  | Capacitor_SMD:C_0603_1608Metric | ~
C7,C13 | 2 | 1 μ |  |  |  | Capacitor_SMD:C_0603_1608Metric | ~
C8,C11 | 2 | 4700 μ |  |  |  | bird-feeder:electrolytic_CAPPRD500W65D1000H2700 | http://industrial.panasonic.com/cdbs/www-data/pdf/RDF0000/ABA0000C1209.pdf
C10 | 1 | 10 μ |  |  |  | Capacitor_THT:CP_Axial_L10.0mm_D4.5mm_P15.00mm_Horizontal | ~
C14 | 1 | 10 μ |  |  |  | bird-feeder:CAPRB250W50L400T250H550 | ~
D1,D3,D4,D5 | 4 | SS34 |  |  |  | Diode_THT:D_DO-41_SOD81_P10.16mm_Horizontal | http://www.diodes.com/_files/datasheets/ds23022.pdf
D2,D6 | 2 | 1N5818 |  |  |  | Diode_THT:D_DO-41_SOD81_P10.16mm_Horizontal | http://www.diodes.com/_files/datasheets/ds23022.pdf
D7,D8 | 2 | 1N4148 |  |  |  | Diode_THT:D_DO-35_SOD27_P7.62mm_Horizontal | https://assets.nexperia.com/documents/data-sheet/1N4148_1N4448.pdf
IC1,IC4 | 2 | NE555 |  |  |  | bird-feeder:LMC555_DIP794W53P254L959H508Q8N | http://www.ti.com/lit/ml/mpdi001b/mpdi001b.pdf
J1,J17 | 2 | Li-Po battery |  |  |  | bird-feeder:ARK raster 2,54 mm | ~
J2,J18 | 2 | Screw_Terminal_01x02 |  |  |  | bird-feeder:ARK raster 2,54 mm | ~
J3,J6 | 2 | 5V_DC/DC |  |  |  | bird-feeder:pin_2_RHDR4W60P0X254_1X4_1016X250X840P_1 | https://www.tme.eu/Document/951e887d7e645db1a4e49e0834499c9b/zl262-sg.pdf
J4,J7,J15,J16 | 4 | Solar panel |  |  |  | bird-feeder:ARK raster 2,54 mm | ~
J5,J12 | 2 | servo |  |  |  | bird-feeder:pin_4_RHDR4W60P0X254_1X4_1016X250X840P | https://www.tme.eu/Document/951e887d7e645db1a4e49e0834499c9b/zl262-sg.pdf
J8,J14 | 2 | ultrasonic |  |  |  | bird-feeder:pin_4_RHDR4W60P0X254_1X4_1016X250X840P | https://www.tme.eu/Document/951e887d7e645db1a4e49e0834499c9b/zl262-sg.pdf
J9,J13 | 2 | UART |  |  |  | bird-feeder:pin_4_RHDR4W60P0X254_1X4_1016X250X840P | https://www.tme.eu/Document/951e887d7e645db1a4e49e0834499c9b/zl262-sg.pdf
J10,J11 | 2 | pin_2 |  |  |  | bird-feeder:pin_2_RHDR4W60P0X254_1X4_1016X250X840P_1 | https://www.tme.eu/Document/951e887d7e645db1a4e49e0834499c9b/zl262-sg.pdf
J19 | 1 | ESP |  |  |  | bird-feeder:ARK raster 2,54 mm | ~
L1,L2 | 2 | ETQP4M150KFN |  |  |  | bird-feeder:DE1207
LED1,LED2 | 2 | 5 V |  |  |  | bird-feeder:LEDC2012X40N
Q1,Q2 | 2 | IRLML2502TRPBF |  |  |  | bird-feeder:IRL_SOT95P237X112-3N
Q3,Q4 | 2 | IRF740 |  |  |  | Library:IRF740
R1 | 1 | 9 k |  |  |  | Resistor_SMD:R_0603_1608Metric | ~
R2 | 1 | 20 k |  |  |  | Resistor_SMD:R_0603_1608Metric | ~
R3,R6,R15,R16 | 4 | 470 |  |  |  | Resistor_SMD:R_0603_1608Metric | ~
R4,R14 | 2 | 20k |  |  |  | Resistor_THT:R_Axial_DIN0204_L3.6mm_D1.6mm_P5.08mm_Horizontal | ~
R5,R13,R20 | 3 | 10k |  |  |  | Resistor_THT:R_Axial_DIN0204_L3.6mm_D1.6mm_P5.08mm_Horizontal | ~
R7,R9,R10,R11 | 4 | 100k |  |  |  | Resistor_THT:R_Axial_DIN0204_L3.6mm_D1.6mm_P5.08mm_Horizontal | ~
R8 | 1 | 100k |  |  |  | Resistor_SMD:R_0603_1608Metric | ~
R12,R19 | 2 | 100 |  |  |  | Resistor_SMD:R_0603_1608Metric | ~
R17 | 1 | 15 k |  |  |  | Resistor_SMD:R_0603_1608Metric | ~
R18 | 1 | 1 k |  |  |  | Resistor_SMD:R_0603_1608Metric | ~
U1,U4 | 2 | TP4056 |  |  |  | bird-feeder:TP4056
U2,U3 | 2 | ESP32-CAM |  |  |  | Library:ESP32-CAM
Z1,Z2 | 2 | 1SMB5918BT3G |  |  |  | bird-feeder:zenner_DIOM5436X247N | https://www.onsemi.com/pub/Collateral/1SMB5913BT3-D.PDF

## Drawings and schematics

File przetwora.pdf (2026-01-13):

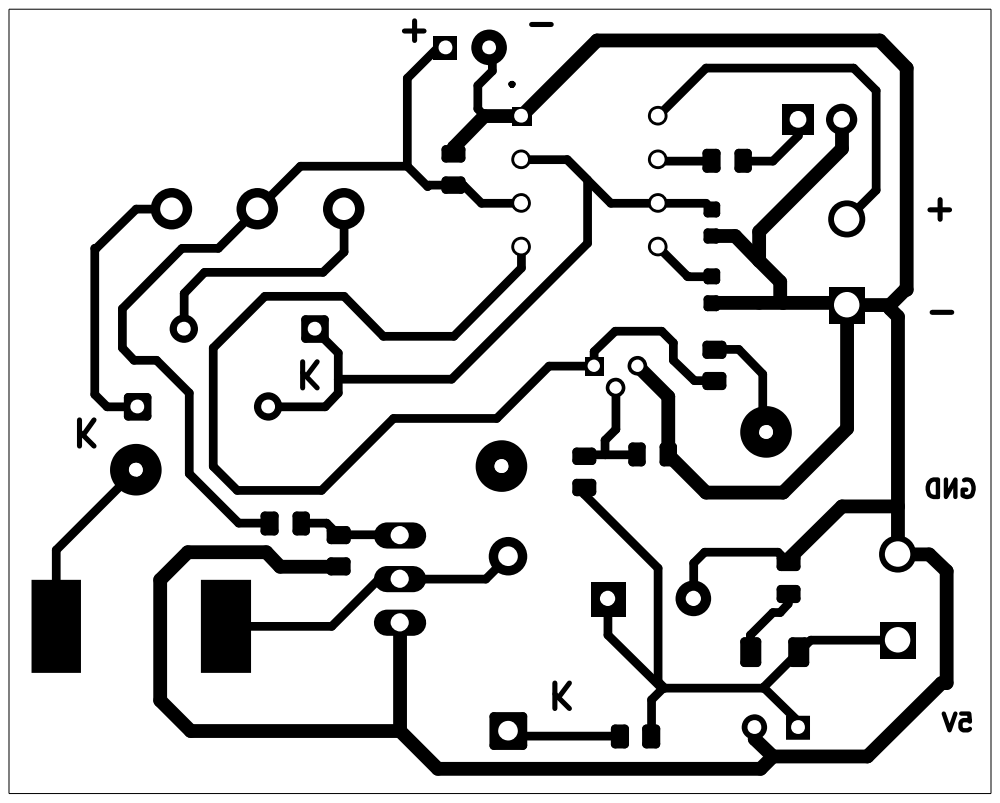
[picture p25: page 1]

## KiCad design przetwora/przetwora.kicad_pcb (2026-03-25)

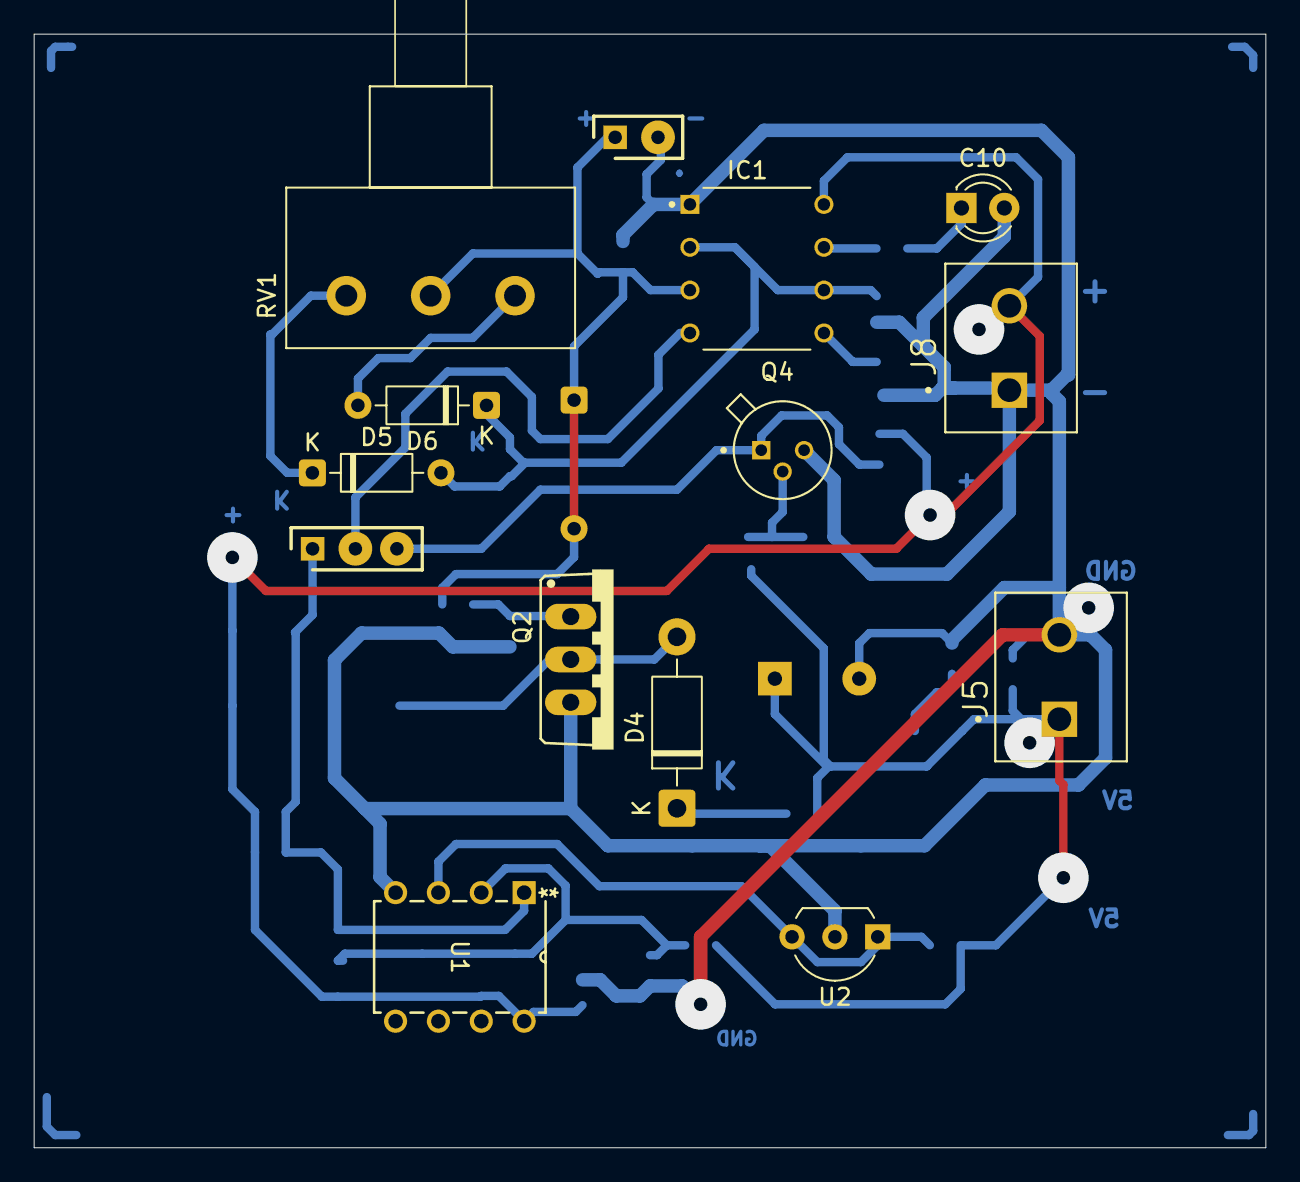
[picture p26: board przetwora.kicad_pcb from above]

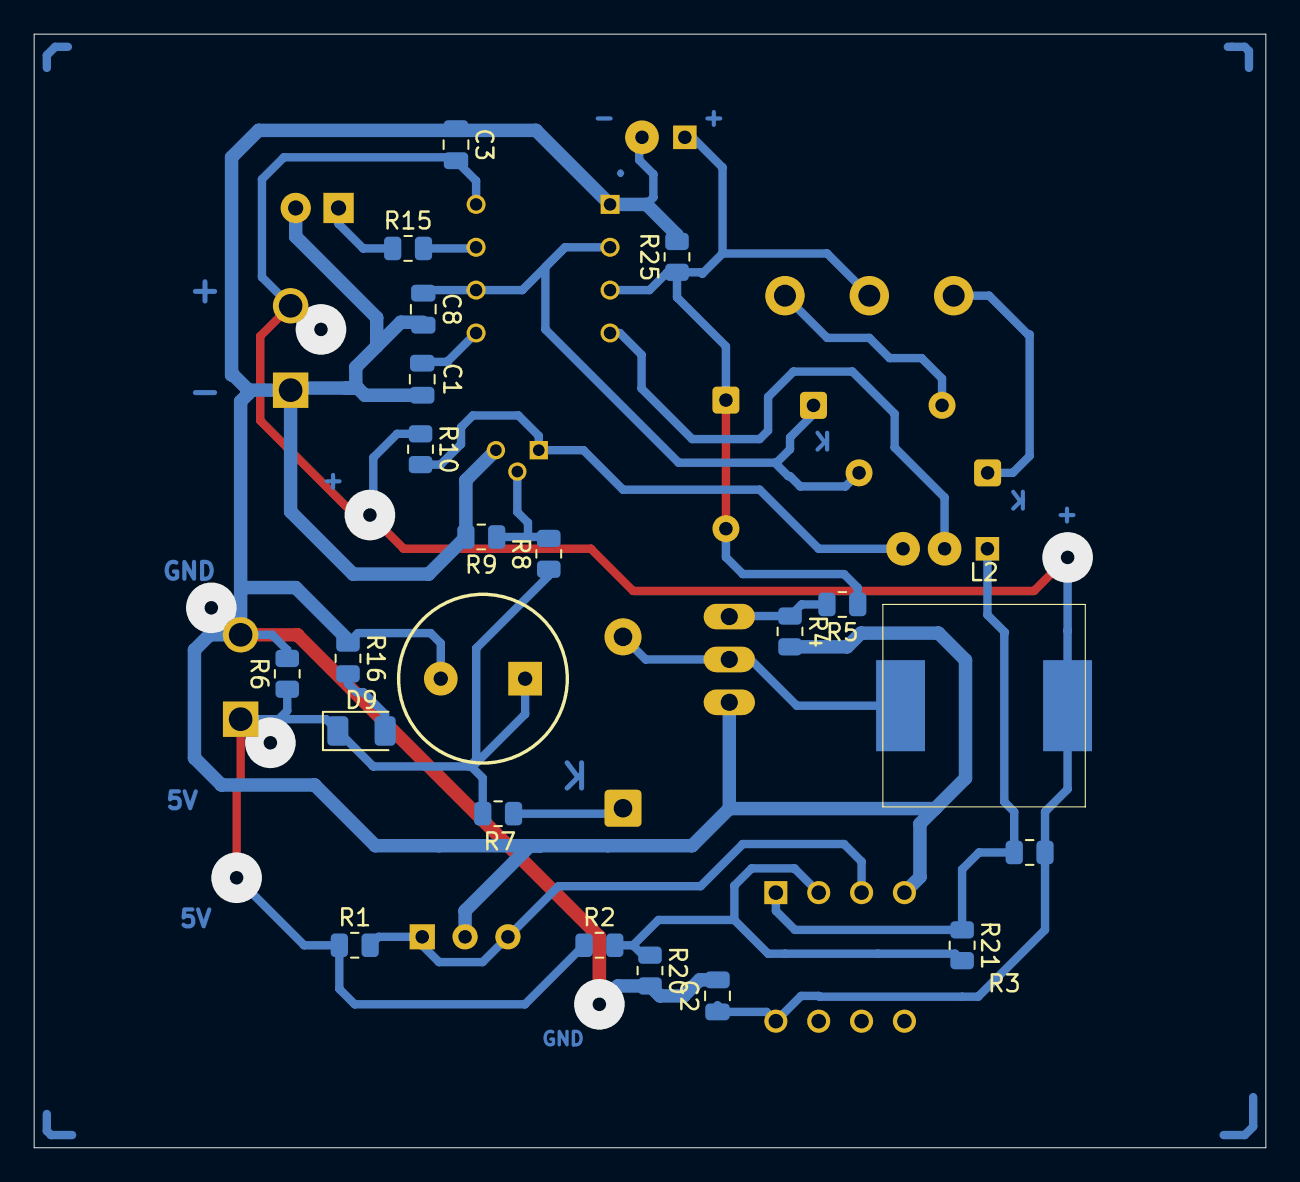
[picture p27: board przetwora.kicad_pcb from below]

Board: 2 copper layers, 73.0 x 66.0 mm, 37 parts (22 on the bottom side), 18 nets.

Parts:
C1, C8: 10n; C_0805_2012Metric
C2, C3: 100n; C_0805_2012Metric
C8#2: 4700 μ; electrolytic_CAPPRD500W65D1000H2700
C10: 100n; LED_D3.0mm
D4: 1N5818; D_DO-41_SOD81_P10.16mm_Horizontal
D5, D5#2, D6: 1N4148; D_DO-35_SOD27_P7.62mm_Horizontal
D9: 5.1 V; D_1206_3216Metric
IC1: lmc555; LMC555
J5: 5V_step_up; roaster_3_5
J6, J6#2: cont_3_5; pin_2_RHDR4W60P0X254_1X4_1016X250X840P_1
J8: baterry; roaster_3_5
L2: ETQP4M150KFN; cewka_DE1207
Q2: IRF740; irf740_TO220BV
Q4: NPN; 2N2222_TO127P580H530-3
R1: 680; R_0805_2012Metric
R2, R3, R4, R15, R20, R25: 10k; R_0805_2012Metric
R5, R10: 100; R_0805_2012Metric
R6: load test; R_0805_2012Metric
R7: 6.8; R_0805_2012Metric
R8: 4.7k; R_0805_2012Metric
R9: 1k; R_0805_2012Metric
R16: 470; R_0805_2012Metric
R21: 470k; R_0805_2012Metric
RV1: 10k; Potentiometer_Omeg_PC16BU_Horizontal
U1: LM393P; LM393
U2: TL431D; TO-92L_Inline_Wide

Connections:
+2V5: R1.2, U1.3 (1IN+), U2.1 (K), U2.3 (REF)
BAT: C2.1, C3.2, IC1.8 (V+), J8.2, L2.2, R3.1, R10.1, U1.8 (VCC)
GND: C1.2, C2.2, C3.1, C8.2, C10.2 (A), IC1.1 (GND), J5.2, J8.1, Q2.S, Q4.3 (E), R4.2, R6.2, R9.2, R16.1, R20.2, R25.2, U1.4 (GND), U2.2 (A)
unnamed: D4.1 (K), R7.1
unnamed: C10.1 (K), R15.1
unnamed: D4.2 (A), L2.1, Q2.D
unnamed: D5.1 (K), RV1.3
unnamed: D6.2 (A), RV1.1
unnamed: D9.2 (A), R16.2
unnamed: C1.1, IC1.5 (CV)
unnamed: IC1.7 (DIS), R15.2
unnamed: Q2.G, R4.1, R5.2
unnamed: Q4.2 (B), R8.2, R9.1
unnamed: R2.2, R20.1, R21.2, U1.2 (1IN-)
PWM_out: D5#2.1 (K), D5#2.2 (A), IC1.3 (OUT), R5.1, R25.1, RV1.2
reset: IC1.4 (~RST), J6.1, J6.2, J6.3 (2), Q4.1 (C), R3.2, R10.2, R21.1, U1.1 (1OUT)
step_up: D9.1 (K), J5.1, R1.1, R2.1, R6.1, R7.2, R8.1
trig: C8.1, D5.2 (A), D6.1 (K), IC1.2 (~TRIG), IC1.6 (THRS)

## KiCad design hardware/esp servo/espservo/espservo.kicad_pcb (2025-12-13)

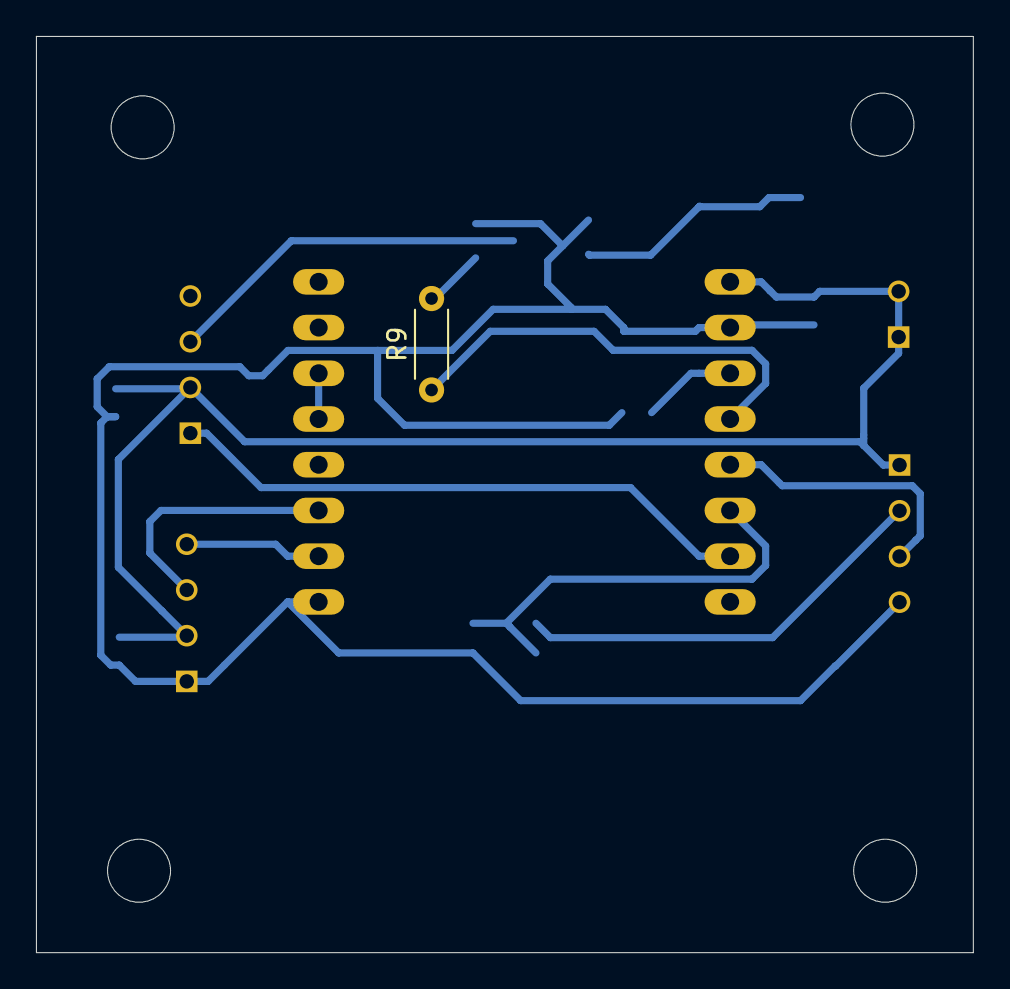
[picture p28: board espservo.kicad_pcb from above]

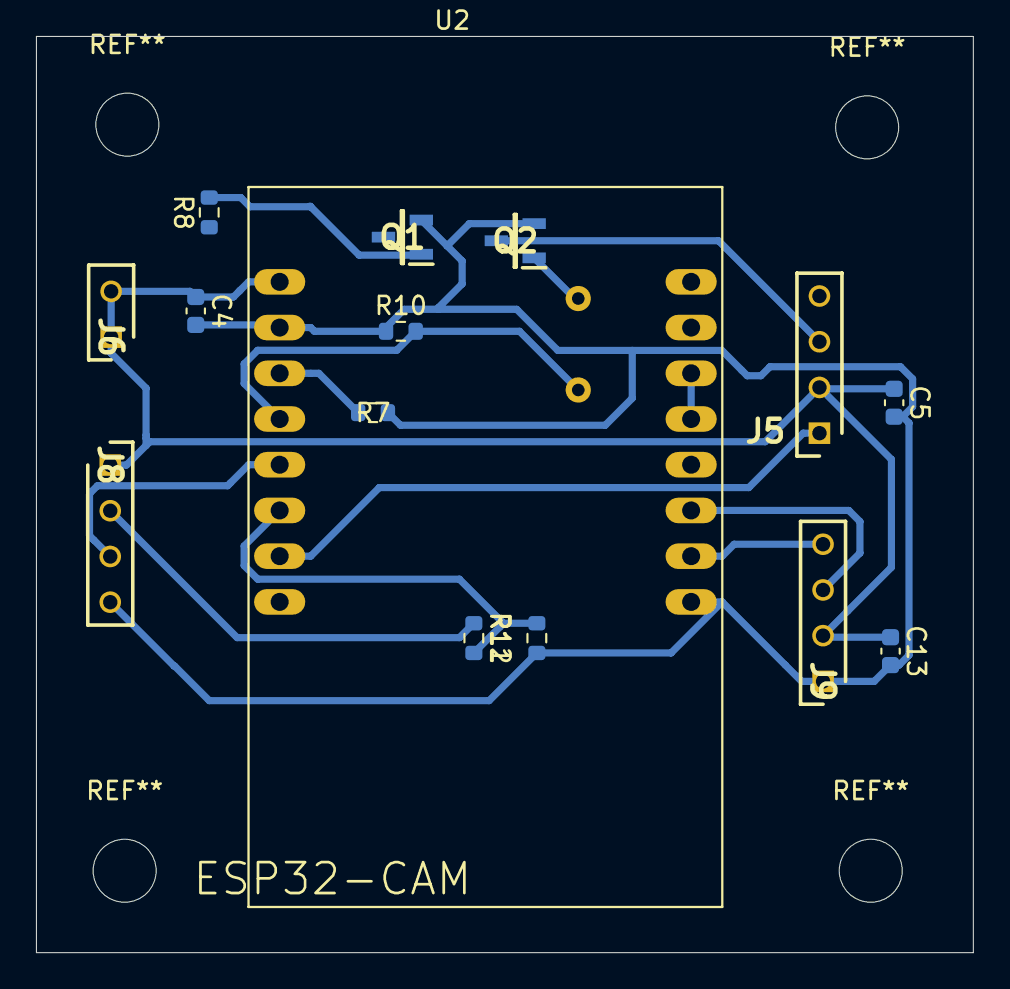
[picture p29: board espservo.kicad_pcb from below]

Board: 2 copper layers, 52.0 x 50.9 mm, 16 parts (15 on the bottom side), 14 nets.

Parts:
C4: 10 μ; C_0603_1608Metric
C5: 100 μ; C_0603_1608Metric
C13: 1 μ; C_0603_1608Metric
J5: servo; pin_4_RHDR4W60P0X254_1X4_1016X250X840P
J6: 5V_DC/DC; pin_2_RHDR4W60P0X254_1X4_1016X250X840P_1
J8: ultrasonic; pin_4_RHDR4W60P0X254_1X4_1016X250X840P
J9: UART; pin_4_RHDR4W60P0X254_1X4_1016X250X840P
Q1, Q2: IRLML2502TRPBF; IRL_SOT95P237X112-3N
R7, R10: 100 k; R_0603_1608Metric
R8: 100; R_0603_1608Metric
R9: 100; R_Axial_DIN0204_L3.6mm_D1.6mm_P5.08mm_Horizontal
R11: 10 k; R_0603_1608Metric
R12: 20 k; R_0603_1608Metric
U2: ESP32-CAM

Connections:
+5V: C4.1, C5.1, C13.1, J5.2, J6.1, J6.2, J8.1, J9.2, U2.P$1 (5V)
GND: C4.2, C5.2, C13.2, J8.4, J9.1, Q1.2 (S), Q2.2 (S), R7.1, R10.1, R12.2, U2.P$2 (GND), U2.P$9 (.GND)
unnamed: Q1.1 (G), R8.2
unnamed: Q2.1 (G), R9.2
unnamed: U2.P$13 (GND.), U2.P$14 (IO0)
unnamed: R7.2, R8.1, U2.P$3 (IO12)
unnamed: R9.1, R10.2, U2.P$4 (IO13)
unnamed: R11.2, R12.1, U2.P$6 (IO14)
UOR: J9.3, U2.P$11 (IO3/U0R)
UOT: J9.4, U2.P$10 (IO1/U0T)
echo: J8.2, R11.1
servo_GND: J5.3, Q2.3 (D)
servo_PWM: J5.1, U2.P$7 (IO2)
trig: J8.3, U2.P$5 (IO15)

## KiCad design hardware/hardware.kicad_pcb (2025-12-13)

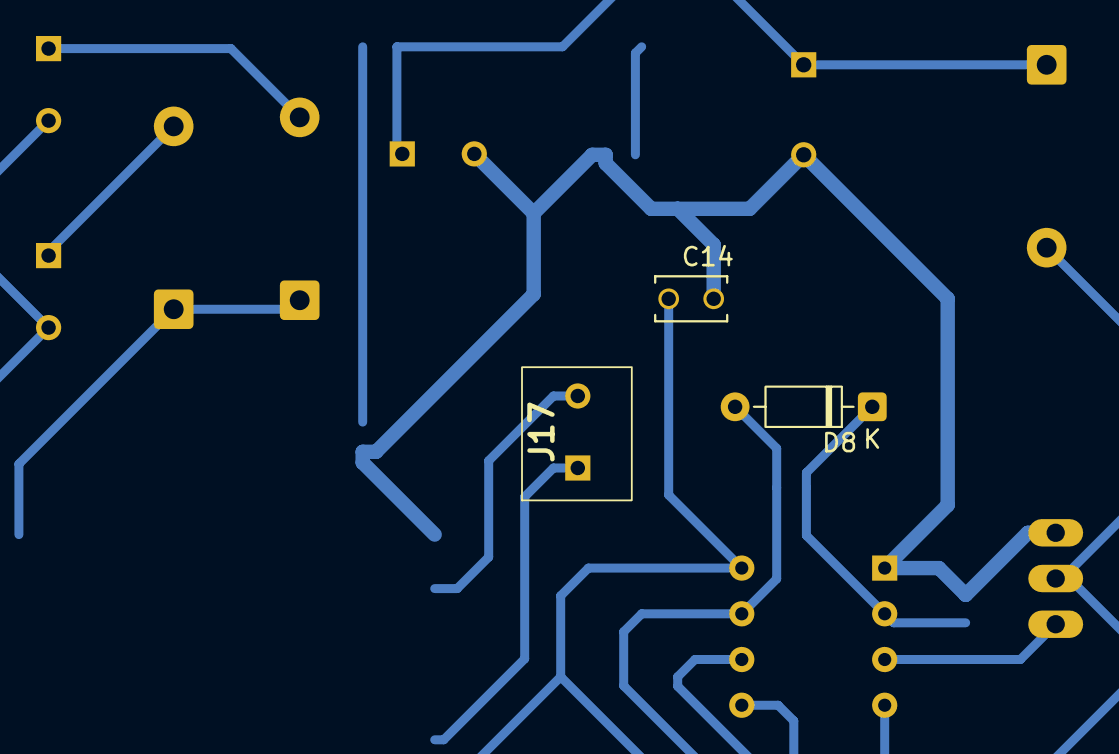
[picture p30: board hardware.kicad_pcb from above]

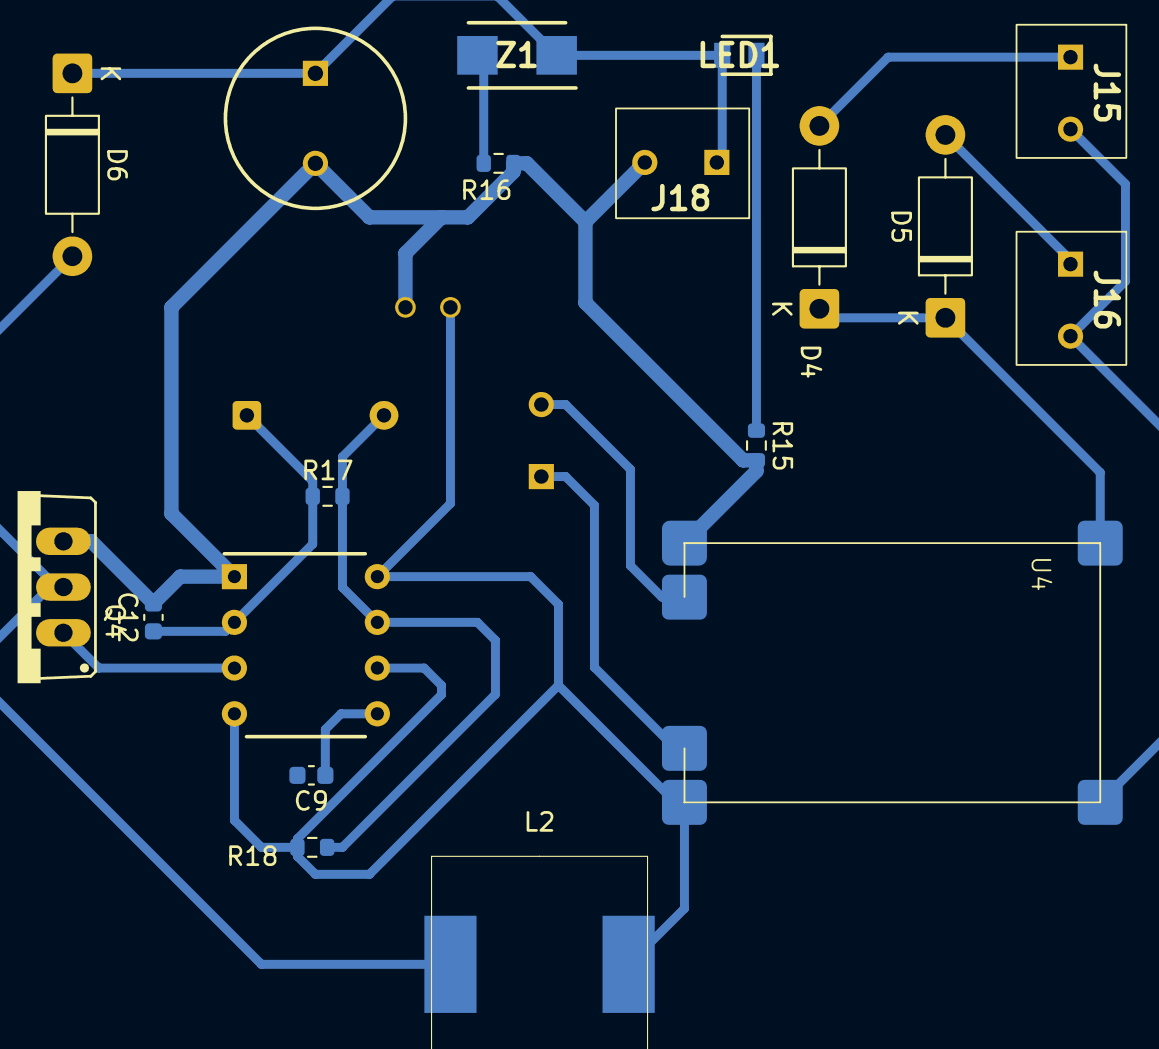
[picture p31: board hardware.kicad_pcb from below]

Board: 2 copper layers, 22 parts (19 on the bottom side), 16 nets.

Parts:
C8: 4700 μ; electrolytic_CAPPRD500W65D1000H2700
C9, C12: 1 n; C_0603_1608Metric
C14: 10 μ; CAPRB250W50L400T250H550
D4, D5: SS34; D_DO-41_SOD81_P10.16mm_Horizontal
D6: 1N5818; D_DO-41_SOD81_P10.16mm_Horizontal
D8: 1N4148; D_DO-35_SOD27_P7.62mm_Horizontal
IC1: NE555; LMC555_DIP794W53P254L959H508Q8N
J15, J16: Solar panel; ARK raster 2,54 mm
J17: Li-Po battery; ARK raster 2,54 mm
J18: Screw_Terminal_01x02; ARK raster 2,54 mm
L2: ETQP4M150KFN; DE1207
LED1: 5 V; LEDC2012X40N
Q4: IRF740
R15, R16: 470; R_0603_1608Metric
R17: 15 k; R_0603_1608Metric
R18: 1 k; R_0603_1608Metric
U4: TP4056
Z1: 1SMB5918BT3G; zenner_DIOM5436X247N

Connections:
+5V: C8.1 (+), D6.1 (K), J18.1, LED1.2 (A), Z1.1 (K)
BAT: C14.1, IC1.4 (~RESET), IC1.8 (V+), L2.2, R18.2, U4.3 (OUT_+)
GND: C8.2 (-), C9.2, C12.2, C14.2, IC1.1 (GROUND), J18.2, Q4.S, R15.2, R16.2, U4.6 (OUT_-)
unnamed: D4.2 (A), J15.1
unnamed: D4.1 (K), D5.1 (K), U4.1 (+)
unnamed: D5.2 (A), J16.1
unnamed: D6.2 (A), L2.1, Q4.D
unnamed: D8.2 (A), IC1.7 (DISCHARGE), R17.2, R18.1
unnamed: C12.1, D8.1 (K), IC1.2 (~TRIGGER), R17.1
unnamed: C9.1, IC1.5 (CONTROL_VOLTAGE)
unnamed: J15.2, J16.2, U4.2 (-)
unnamed: J17.1, U4.4 (B_+)
unnamed: J17.2, U4.5 (B_-)
unnamed: LED1.1 (K), R15.1
unnamed: R16.1, Z1.2 (A)
PWM: IC1.3 (OUTPUT), Q4.G

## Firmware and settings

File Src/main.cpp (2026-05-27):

// Src/main.cpp

#include <Arduino.h>
#include <WiFi.h>
#include "config.h"
#include "sensors_n_actuators/wifi_meneger/wifi_meneger.h"
#include "sensors_n_actuators/pir_sensor/pir_sensor.h"
#include "sensors_n_actuators/camera/camera.h"
#include "telegram/telegram.h"

// Setup
PIRSensor pirSensor(PIR_SENSOR_PIN, PIR_ACTIVE_LEVEL);
TelegramManager telegramBot;
bool wifiReady = false;
bool telegramReady = false;
bool cameraReady = false;
String mode = "None";

// Utils (Prototypes, definitions at the end of this file)
bool captureAndSendPhoto();
bool telegramIntroMessage();
void telegramMainLoopIntroMessage();
void handleTelegramCommandInMainLoop();
void helpMessage();
String buildStatusMessage();
void testPirSensor();
void runSilentMode();


// Initialization
void setup() {
#if DEBUG_STARTUP

    // Initialize Serial
    Serial.begin(115200);
    delay(3000); // Coucious delay to allow Serial monitor to connect

    // Test PIR
    Serial.println("Testing PIR sensor.");
    pirSensor.begin();
    Serial.println("Outputting PIR state every third of a second.");
    while (true) {
        delay(333);

        bool rawHigh = pirSensor.readDigital();
        bool motion = pirSensor.isMotionDetected();

        Serial.print("raw=");
        Serial.print(rawHigh ? "HIGH" : "LOW");
        Serial.print(" motion=");
        Serial.println(motion ? "YES" : "NO");
    }
#else // Normal setup() ( DEBUG_STARTUP = 0 )
    String fullDebugMessage = "";
    String briefDebugMessage = "";

    // Initialize Serial
    Serial.begin(115200);
    delay(3000); // Coucious delay to allow Serial monitor to connect
    Serial.println("\n\n[SYSTEM] Starting up ESP32-CAM bird feeder system...\n\n");

// DEBUG - config info
#if DEBUG_SERIAL
    //Serial.println("\n");
    //Serial.println("<<<----- DEBUG MODE ----->>>");
    Serial.println("[CONFIG] Loaded successfully");
    Serial.print("[CONFIG] SSID: ");
    Serial.println(SSID_1);
    Serial.print("[CONFIG] PIR pin: ");
    Serial.println(PIR_SENSOR_PIN);
    Serial.print("[CONFIG] Flash LED pin: ");
    Serial.println(FLASH_LED_PIN);
    //Serial.println("<<<--- END DEBUG MODE --->>>\n");
#endif

    // Config info
    briefDebugMessage += "Config loaded successfully.\n";
    fullDebugMessage += "Config loaded successfully:\n";
    fullDebugMessage += "Debug mode:\n\tSERIAL=" + String(DEBUG_SERIAL ? "ON" : "OFF");
    fullDebugMessage += ",\n\tWIFI=" + String(DEBUG_SERIAL_WIFI ? "ON" : "OFF");
    fullDebugMessage += ",\n\tTELEGRAM=" + String(DEBUG_SERIAL_TELEGRAM ? "ON" : "OFF");
    fullDebugMessage += ",\n\tMESSAGE_COUNTER=" + String(DEBUG_MESSAGE_COUNTER ? "ON" : "OFF") + ".\n";
    fullDebugMessage += ",\nPIR sensor test - message frequency=" + String(float(DEBUG_PIR_TEST_MESSAGE_FREQUENCY)/10) + "s.\n\n";
    
    // Connect to WiFi
    delay(100); // Small cautious delay before starting WiFi connection
    wifiReady = connectToWiFi(WIFI_CONNECTION_TIMEOUT); // 2 minutes timeout for WiFi connection
    if (!wifiReady) {
        Serial.println("[SYSTEM] WiFi not available. Stopping further initialization.");
        return;
    }
    Serial.println("[SYSTEM] WiFi connected!");
    briefDebugMessage += "WiFi connected.\n";
    fullDebugMessage += "WiFi connected successfully:\n";
    fullDebugMessage += "SSID:\t" + WiFi.SSID()+ "\n";
    fullDebugMessage += "IP address:\t" + WiFi.localIP().toString() + "\n";
    fullDebugMessage += "Signal strength (RSSI):\t" + String(WiFi.RSSI()) + " dBm\n";
    fullDebugMessage += "WiFi channel:\t" + String(WiFi.channel()) + "\n";
    fullDebugMessage += "WiFi connection timeout: " + String(float(WIFI_CONNECTION_TIMEOUT)/6000) + "min\n\n";

    // Initialize Telegram bot
    delay(400); // Cautious delay before initializing Telegram
    telegramBot.begin();
    telegramBot.clearPendingMessages();
    Serial.println("[SYSTEM] Telegram bot initialized, testing connection...");
    if (!telegramReady) {
        Serial.println("[SYSTEM] Telegram test failed.");
    } else {
        Serial.println("[SYSTEM] Telegram test passed.");
    }
    telegramReady = telegramIntroMessage();
    briefDebugMessage += "Telegram bot initialized.\n";
    fullDebugMessage += "Telegram bot initialized successfully:\n";
    fullDebugMessage += "Bot token:\t" + String(BOT_TOKEN).substring(0, 2) + "  ...  " + String(BOT_TOKEN).substring(String(BOT_TOKEN).length() - 2) + "\n";
    fullDebugMessage += "Chat ID:\t" + String(CHAT_ID).substring(0, 2) + "  ...  " + String(CHAT_ID).substring(String(CHAT_ID).length() - 2) + "\n";
    fullDebugMessage += "Request delay:\t" + String(BOT_REQUEST_DELAY) + " ms\n";
    fullDebugMessage += "Response delay:\t" + String(BOT_RESPONSE_DELAY) + " ms\n\n";

    // Initialize camera
    delay(600); // Cautious delay before initializing camera
    Serial.println("[SYSTEM] Initializing camera...");
    cameraReady = initCamera();
    // Test photo capture
    delay(100); // Cautious delay before testing photo capture
    Serial.println("[SYSTEM] Single photo capture test.");
    if (!cameraReady) {
        Serial.println("[PHOTO] Skipped: camera not ready.");
    } else{
        camera_fb_t* photo = capturePhoto();
        if (photo == nullptr) {
            Serial.println("[PHOTO] Capture failed.");
        } else {
            Serial.println("[PHOTO] Photo captured.");
            releasePhoto(photo); // Release the photo buffer after testing capture to prevent memory leaks
        }
    }
    briefDebugMessage += "Camera capture tested successfully.\n";
    fullDebugMessage += "Camera initialized successfully:\n";
    fullDebugMessage += "Camera model:\tOV2640-75MM\n";
    fullDebugMessage += "Camera resolution:\t<Not implemented>\n";
    fullDebugMessage += "Camera frame size:\t<Not implemented>\n";
    fullDebugMessage += "Camera capture tested successfully.\n\n";

    // Initialize PIR sensor
    Serial.println("[SYSTEM] Initializing PIR sensor...");
    pirSensor.begin();
    bool sensorTest = pirSensor.isMotionDetected();
    Serial.println("[SYSTEM] PIR sensor initialized.");
    briefDebugMessage += "PIR sensor initialized.\n";
    fullDebugMessage += "PIR sensor initialized successfully:\n";
    fullDebugMessage += "PIR sensor pin:\t" + String(PIR_SENSOR_PIN) + "\n";
    fullDebugMessage += "PIR sensor active level:\t" + String(PIR_ACTIVE_LEVEL) + "\n";
    fullDebugMessage += "PIR sensor state:\t" + String(sensorTest ? "Motion detected" : "Currently no motion") + "\n";
    fullDebugMessage += "PIR sensor cooldown time:\t" + String(PIR_CAPTURE_COOLDOWN) + "ms.\n\n";

    // Setup complete message and intro information
    Serial.println("[SYSTEM] Initialization complete.");
    while (true) {
        TelegramCommand introCommand = telegramBot.handleMessages();

        if (introCommand == TelegramCommand::None) {
            delay(BOT_RESPONSE_DELAY);
            continue;
        } if (introCommand == TelegramCommand::init) {
            telegramBot.sendMessage("Initialization complete. Running in silent automatic mode.");
            mode = "Silent";
            break;
        } if (introCommand == TelegramCommand::init_debug) {
            telegramBot.sendMessage(briefDebugMessage);
            break;
        } if (introCommand == TelegramCommand::init_full) {
            telegramBot.sendMessage(fullDebugMessage);
            telegramBot.sendMessage("Sending full help message with available commands...");
            helpMessage();
            break;
        } telegramBot.sendMessage("Use /init, /init_debug, or /init_full to finish initialization.");

        delay(BOT_RESPONSE_DELAY);
    }

#endif
    delay(100); // Small delay before entering main loop (sanity check)
}

// Entry point
void loop() {
#if DEBUG_STARTUP
    // pass
#else // DEBUG_STARTUP = 0

    // Util for controlled delays
    unsigned long startTime = millis();

    // If we're in "None" mode, we wait for the user to choose a mode via Telegram commands.
    if (mode == "None") {
        // Send intro message with available commands
        telegramMainLoopIntroMessage();

        // Check for Telegram commands
        while (mode == "None") {
            const unsigned long now = millis();
            if (now - startTime >= BOT_RESPONSE_DELAY){
                handleTelegramCommandInMainLoop();
                startTime = now;
            }
            delay(10);
        }
    }

    // Main loop
    startTime = millis();
    while (mode != "None") {

        // Utils for controlled delays
        const unsigned long now = millis();
        if (now - startTime >= BOT_REQUEST_DELAY){
            // Check for Telegram commands
            handleTelegramCommandInMainLoop();
            // Reset start time
            startTime = now;
        }
        delay(10);
    }
#endif
}   


// Utils - definitions
bool telegramIntroMessage(){
    telegramBot.sendMessage(
    "🌿🟢🌿🟢🌿🟢🌿🟢🌿\n"
    "\n"
    "  🐦 BIRD FEEDER SYSTEM\n"
    "\n"
    "  🚀 STARTING UP...\n"
    "\n"
    "🌿🟢🌿🟢🌿🟢🌿🟢🌿");

    String intro = "Hello! I'm your friendly neighborhood bird feeder system, powered by ESP32-CAM.";
    intro += " I'm here to keep an eye on your feathered friends and share their photos with you!\n";
    intro += "What should I do now?\nHere are some commands you can use:\n";
    intro += "/init - initialize the system quaietly, report success and run silent automatic mode\n";
    intro += "/init_debug - initialize the system with brief debug output\n";
    intro += "/init_full - initialize the system with full debug output\n";
    intro += "Keep in mind that initialization might take up to a minute ;)";
    return telegramBot.sendMessage(intro);
}

void telegramMainLoopIntroMessage() {
    telegramBot.sendMessage(
        "🌿🟢🌿🟢🌿🟢🌿🟢🌿\n"
        " 🐦 BIRD FEEDER SYSTEM\n"
        "🌿🟢🌿🟢🌿🟢🌿🟢🌿\n"
        "\n"
        "System ready.\n"
        "\n"
        "Available basic commands:\n"
        "\n"
        "📖 /help\n"
        "Show available commands.\n"
        "\n"
        "🌙 /run_silent\n"
        "Start silent automatic mode.\n"
        "The feeder sends a photo only when PIR detects motion.\n"
        "\n"
        "🛠 /run_debug\n"
        "Start automatic mode with debug messages.\n"
        "\n"
        "🛑 /stop\n"
        "Stop automatic mode.\n"
    );
}

bool captureAndSendPhoto() {
    if (!isWiFiConnected()) {
        Serial.println("[PHOTO] Skipped: WiFi disconnected.");
        return false;
    }

    if (!cameraReady) {
        Serial.println("[PHOTO] Skipped: camera not ready.");
        telegramBot.sendMessage("Photo skipped: camera not ready.");
        return false;
    }

    camera_fb_t* photo = capturePhoto();

    if (photo == nullptr) {
        Serial.println("[PHOTO] Capture failed.");
        telegramBot.sendMessage("Photo capture failed.");
        return false;
    }

    Serial.println("[PHOTO] Sending photo to Telegram...");

    const bool sent = telegramBot.sendPhoto(photo->buf, photo->len);

    releasePhoto(photo);

    if (sent) {
        Serial.println("[PHOTO] Photo sent successfully.");
    } else {
        Serial.println("[PHOTO] Photo sending failed.");
        telegramBot.sendMessage("Photo sending failed.");
    }

    return sent;
}

void handleTelegramCommandInMainLoop() {    
    // Get the latest command from Telegram
    TelegramCommand command = telegramBot.handleMessages();
    Serial.println("[TELEGRAM] Checking for a command: " + String(telegramBot.commandToString(command)));

    switch (command) {
        // None - No command received, do nothing
        case TelegramCommand::None:
            mode = "None";
            break;

        // Start - not implemented yet

        // Help - Send help message. Do not change mode
        case TelegramCommand::Help:
            helpMessage();
            break;

        // Status - not implemented yet
        
        // Test_pir - Run test pir sensor and get back to none
        case TelegramCommand::Test_pir:
            testPirSensor();
            mode = "None";
            break;

        //WiFi_status - not implemented yet

        //Test_camera - not implemented yet

        //Config_info - not implemented yet

        // Run_silent - Run silent mode until it finnishes, then reset to None mode
        case TelegramCommand::Run_silent:
            runSilentMode();
            mode = "None";
            break;

        // Run_debug - Not implemented yet
        case TelegramCommand::Run_debug:
            telegramBot.sendMessage("Starting automatic debug mode. The feeder will send a photo when motion is detected by the PIR sensor.\n"
                                    "Also there will be debug messages sent to the serial monitor and Telegram.");
            // Debug mode here;
            mode = "None";
            break;
        
        // Change_configuration - not implemented yet

        // Reset - Reset ESP with all peripherals
        case TelegramCommand::Reset:
            telegramBot.sendMessage("Feeder will reset now. It might take few seconds...");
            mode = "None";
            Serial.flush();
            delay(200);

            ESP.restart();
            break; // Redundant break to at least reset main loop if ESP.restart() fails.

        // Unknown command. Inform user. Do not change mode.
        default:
            telegramBot.sendMessage("Unsupported command received. Try again.\nUse /help to see available commands.");
            break;
    }
}

void helpMessage() {
    telegramBot.sendMessage(
        "BIRD FEEDER SYSTEM - COMMANDS\n"
        "\n"
        "\n"
        "Basic commands:\n"
        "/start - show intro message\n"
        "/help - show this command list\n"
        "/status - show general system status [in development]\n"
        "\n"
        "Initialization commands:\n"
        "/init - initialize quietly and run silent automatic mode\n"
        "/init_debug - initialize with brief debug output\n"
        "/init_full - initialize with full debug output\n"
        "\n"
        "Test commands:\n"
        "/test_pir - test PIR sensor\n"
        "/wifi_status - show WiFi status [in development]\n"
        "/test_camera - test camera capture [in development]\n"
        "/config_info - show selected config info [in development]\n"
        "\n"
        "Run commands:\n"
        "/run_silent - start silent automatic mode\n"
        "/run_debug - start automatic debug mode [in development]\n"
        "/stop - stop automatic mode\n"
        "/change_config - change selected config parameters [in development]\n"
        "/restart - resets the ESP board with all periferies."
    );
}

void testPirSensor() {
    bool state = false;
    String message;
    message.reserve(2048);
    String frequencyForMessages = String(float(DEBUG_PIR_TEST_MESSAGE_FREQUENCY)/10);
    message = "PIR raport from last " + frequencyForMessages + "s:\n\n";
    unsigned long testStartTime = millis();
    unsigned long lastSampleTime = 0;
    unsigned long lastReportTime = millis();
    unsigned long lastTelegramCheckTime = millis();

    // Initialize test
    telegramBot.sendMessage(
        "PIR test started.\n"
        "Send /stop to finish.\n\n"
        "Pin: " + String(pirSensor.getPin()) + "\n"
        "Active level: " + String(pirSensor.getActiveLevel()) + "\n\n"
        "Feeder will collect PIR sensor state every tenth of a second and send it acumulated every" + frequencyForMessages + 
        "s. It will also send live data via UART interface.\n\n"
        "Listening for motion..."
    );
    Serial.println("[PIR TEST] Simple test started.");

    while (true){
        const unsigned long now = millis();

        // Check telegram messages for \stop and \help
        if (now - lastTelegramCheckTime >= BOT_REQUEST_DELAY) {
            lastTelegramCheckTime = now;
            TelegramCommand lastMessage = telegramBot.handleMessages();

            // /stop
            if (lastMessage == TelegramCommand::Stop) {
                telegramBot.sendMessage("Stopping PIR sensor test.");
                telegramBot.sendMessage(message);
                mode = "None";
                return;
            
            // /help
            } else if (lastMessage == TelegramCommand::Help) helpMessage();
        }

        // Get PIR state
        bool rawHigh = pirSensor.readDigital();
        bool motion = pirSensor.isMotionDetected();

        // Write messages
        float t = (now - testStartTime) / 1000.0f;
        Serial.print("[PIR TEST] Raw signal: ");
        Serial.print(rawHigh ? "HIGH" : "LOW");
        Serial.print(", motion: ");
        Serial.println(motion ? "YES" : "NO");
        message += String(t, 1) + "s  -  Raw signal: " + String(rawHigh ? " < HIGH > " : " < LOW > ");
        message += ", Motion: " + String(motion ? " < YES > " : " < NO > ") + ".\n";
        message += ".\n";

        // send telegram message
        if (now - lastReportTime >= DEBUG_PIR_TEST_MESSAGE_FREQUENCY) {
            lastReportTime = now;

            telegramBot.sendMessage(message);
            message = "PIR raport from last 5s:\n\n";
        }

        delay(10);
    }
}

void runSilentMode() {
    telegramBot.sendMessage("Starting silent automatic mode.\n"
                            "The feeder will send a photo only when motion is detected by the PIR sensor.\n\n"
                            "Waiting for birds to arrive...");

    unsigned long automaticStartTime = millis();
    unsigned long lastSampleTime = 0;
    unsigned long lastTelegramCheckTime = millis();
    unsigned long lastCaptureTime = 0;
    bool pirWasActive = false;

    // Main loop
    while (true){
        const unsigned long now = millis();
        
        // Check for \stop and \help
        if (now - lastTelegramCheckTime >= BOT_REQUEST_DELAY) {
            lastTelegramCheckTime = now;
            TelegramCommand lastMessage = telegramBot.handleMessages();

            // /stop
            if (lastMessage == TelegramCommand::Stop) {
                telegramBot.sendMessage("Stopping automatic silent mode...");
                mode = "None";
                return;
            // /help
            } else if (lastMessage == TelegramCommand::Help) helpMessage();
        }

        if (now - lastSampleTime >= BOT_REQUEST_DELAY) {
            lastSampleTime = now;
            
            // Get PIR state
            bool motion = pirSensor.isMotionDetected();
        
            // React to new motion
            if (motion && !pirWasActive) {
                const unsigned long now2 = millis();

                if (lastCaptureTime == 0 || now2 - lastCaptureTime >= PIR_CAPTURE_COOLDOWN) {
                    Serial.println("[SILENT MODE] Motion detected.");

                    telegramBot.sendMessage(
                        "Motion detected near the feeder.\n"
                        "Taking photo..."
                    );

                    delay(200); // short delay before capture
                    bool sent = captureAndSendPhoto();

                    lastCaptureTime = millis();

                    if (sent) {
                        Serial.println("[SILENT MODE] Photo sent.");
                    } else {
                        Serial.println("[SILENT MODE] Photo sending failed.");
                    }
                } else {
                    Serial.println("[SILENT MODE] Motion ignored due to cooldown.");
                }
            }
            // Update PIR state memory
            pirWasActive = motion;
        }

        delay(10);
    }
}

// temporary function - not tested
String buildStatusMessage() {
    String status = "Bird Feeder status\n";

    status += "WiFi: ";
    status += isWiFiConnected() ? "OK\n" : "DISCONNECTED\n";

    if (isWiFiConnected()) {
        status += "RSSI: ";
        status += String(WiFi.RSSI());
        status += " dBm\n";
    }

    status += "Camera: ";
    status += cameraReady ? "OK\n" : "NOT READY\n";

    status += "Free heap: ";
    status += String(ESP.getFreeHeap());
    status += " B\n";

    status += "Uptime: ";
    status += String(millis() / 1000);
    status += " s";

    return status;
}

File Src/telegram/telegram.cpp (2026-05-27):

// Src/telegram/telegram.cpp

#include "telegram.h"

TelegramManager::TelegramManager() {}

TelegramManager::~TelegramManager() {
    if (bot != nullptr) {
        delete bot;
    }
#if DEBUG_SERIAL_TELEGRAM
    //Serial.println("\n");
    //Serial.println("<<<----- DEBUG MODE ----->>>");
    Serial.println("[TELEGRAM] Checking bot instance...");
    if (bot == nullptr) {
        Serial.println("[TELEGRAM] Bot instance already nonexistent");
    } else {
        Serial.println("[TELEGRAM] Bot instance still exists, deleting...");
    }
    Serial.println("[TELEGRAM] Bot instance deleted");
    //Serial.println("<<<--- END DEBUG MODE --->>>\n");
#endif
}

void TelegramManager::begin() {
    clientTCP.setCACert(TELEGRAM_CERTIFICATE_ROOT);
    bot = new UniversalTelegramBot(BOT_TOKEN, clientTCP);
    Serial.println("[TELEGRAM] Bot initialized");
#if DEBUG_SERIAL_TELEGRAM
    //Serial.println("\n");
    //Serial.println("<<<----- DEBUG MODE ----->>>");
    Serial.println("[TELEGRAM] Bot instance created");
    //Serial.println("<<<--- END DEBUG MODE --->>>\n");
#endif
}

bool TelegramManager::sendMessage(const String& message) {
    static uint32_t messageCounter = 0;
    messageCounter++;

    String debugMessage = "[MSG #" + String(messageCounter) + "]\n\n" + message;

    if (bot == nullptr) {
        Serial.println("[TELEGRAM] Bot not initialized");
        return false;
    }

#if DEBUG_SERIAL_TELEGRAM
    //Serial.println("\n");
    //Serial.println("<<<----- DEBUG MODE ----->>>");
    Serial.println("[TELEGRAM] Sending message: " + message + " to chat ID: " + String(CHAT_ID) + "...");
    //Serial.println("<<<--- END DEBUG MODE --->>>\n");
#endif

    bool successfully_sent = bot->sendMessage(CHAT_ID, debugMessage, "");

    if (successfully_sent) {
        Serial.println("[TELEGRAM] Message [" + message + "] sent");
    } else {
        Serial.println("[TELEGRAM] Message [" + message + "] sending failed");
    }

    return successfully_sent;
}

bool TelegramManager::sendPhoto(uint8_t* jpgBuffer, size_t jpgSize) {
    // Check buffer validity and return early if invalid
    if (jpgBuffer == nullptr || jpgSize == 0) {
        Serial.println("[TELEGRAM] ERR: Invalid photo buffer");
        return false;
    }
    
    // Send photo via Telegram API and check response
    String response = sendPhotoViaTelegram(jpgBuffer, jpgSize);
    
    // Check if response indicates success
    if (response.length() > 0 && response.indexOf("\"ok\":true") >= 0) {
        Serial.println("[TELEGRAM] Photo sent!");
        return true;
    } else {
        Serial.println("[TELEGRAM] ERR: Failed to send photo");
        Serial.println(response);
        return false;
    }
}

String TelegramManager::sendPhotoViaTelegram(uint8_t* jpgBuffer, size_t jpgSize) {
    const char* domain = "api.telegram.org"; // Telegram API server domain
    String getBody = ""; // To store JSON/HTTP response body from Telegram API
    
    if (clientTCP.connect(domain, 443)) { // 443 is the standard port for HTTPS
        Serial.println("[TELEGRAM] Connected to api.telegram.org");
        
        // Prepare multipart/form-data headers and body for photo upload
        String head = "--Boundary123\r\n";
        head += "Content-Disposition: form-data; name=\"chat_id\"\r\n\r\n";
        head += String(CHAT_ID) + "\r\n";
        head += "--Boundary123\r\n";
        head += "Content-Disposition: form-data; name=\"photo\"; filename=\"esp32-cam.jpg\"\r\n";
        head += "Content-Type: image/jpeg\r\n\r\n";
        
        String tail = "\r\n--Boundary123--\r\n";
        
        size_t totalLen = head.length() + jpgSize + tail.length();
        
        clientTCP.println("POST /bot" + String(BOT_TOKEN) + "/sendPhoto HTTP/1.1");
        clientTCP.println("Host: " + String(domain));
        clientTCP.println("Content-Length: " + String(totalLen));
        clientTCP.println("Content-Type: multipart/form-data; boundary=Boundary123");
        clientTCP.println("Connection: close");
        clientTCP.println();
        clientTCP.print(head);
        
        // Send photo data in 1kB chunks to avoid memory issues with large photos
        uint8_t* buf = jpgBuffer;
        size_t remaining = jpgSize;
        while (remaining > 0) {
            size_t toSend = (remaining > 1024) ? 1024 : remaining;
            clientTCP.write(buf, toSend);
            buf += toSend;
            remaining -= toSend;
        }
        
        clientTCP.print(tail);
        
        // Get response
        unsigned long startTime = millis();

        while (millis() - startTime < 10000) {
            while (clientTCP.available()) {
                char c = clientTCP.read();
                getBody += c;

                // Telegram confirmed success, no need to keep reading until TLS close.
                if (getBody.indexOf("\"ok\":true") >= 0) {
                    clientTCP.stop();
                    return getBody;
                }
            }

            if (!clientTCP.connected()) {
                break;
            }

            delay(10);
        }
        
        clientTCP.stop();
    } else {
        Serial.println("[TELEGRAM] ERR: Connection failed");
    }
    
    return getBody;
}

void TelegramManager::clearPendingMessages(uint8_t rounds) {
    if (bot == nullptr) {
        return;
    }

    for (uint8_t i = 0; i < rounds; i++) {
        int numMessages = bot->getUpdates(bot->last_message_received + 1);

        if (numMessages <= 0) {
            break;
        }

        delay(100);
    }
#if DEBUG_SERIAL_TELEGRAM
    Serial.println("[TELEGRAM] Pending messages cleared");
#endif
}

TelegramCommand TelegramManager::parseCommand(String text) {
    text.trim();

    int mentionPos = text.indexOf('@');
    if (mentionPos > 0) {
        text = text.substring(0, mentionPos);
    }

    // basic commands
    if (text == "/start") return TelegramCommand::Start;
    if (text == "/help") return TelegramCommand::Help;  
    if (text == "/status") return TelegramCommand::Status;
    // initialization commands
    if (text == "/init") return TelegramCommand::init;
    if (text == "/init_debug") return TelegramCommand::init_debug;
    if (text == "/init_full") return TelegramCommand::init_full;
    // test commands
    if (text == "/test_pir") return TelegramCommand::Test_pir;
    if (text == "/wifi_status") return TelegramCommand::WiFi_status;
    if (text == "/test_camera") return TelegramCommand::Test_camera;
    if (text == "/config_info") return TelegramCommand::Config_info;
    // action commands
    if (text == "/run_silent") return TelegramCommand::Run_silent;
    if (text == "/run_debug") return TelegramCommand::Run_debug;
    if (text == "/stop") return TelegramCommand::Stop;
    if (text == "/reset") return TelegramCommand::Reset;

    // default for unknown command
    return TelegramCommand::Unknown;
}
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

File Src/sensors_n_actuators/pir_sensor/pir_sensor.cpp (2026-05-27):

// Src/sensors_n_actuators/pir_sensor/pir_sensoe.cpp

#include "pir_sensor.h"

PIRSensor::PIRSensor(uint8_t sensorPin, uint8_t sensorActiveLevel)
    : pin(sensorPin), activeLevel(sensorActiveLevel) {}

void PIRSensor::begin() {
    pinMode(pin, INPUT);

    Serial.print("[PIR] Initialized on GPIO ");
    Serial.println(pin);

    Serial.print("[PIR] Active level: ");
    Serial.println(activeLevel);
}

bool PIRSensor::readDigital() const {
    return digitalRead(pin) == HIGH;
}

bool PIRSensor::isMotionDetected() const {
    return digitalRead(pin) == activeLevel;
}

uint8_t PIRSensor::getPin() const {
    return pin;
}

uint8_t PIRSensor::getActiveLevel() const {
    return activeLevel;
}

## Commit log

2025-10-26 Aktualny stan projektu
    [BOM.xlsx, hardware.kicad_pcb, hardware.kicad_sch]
2025-10-28 open lab
    [BOM.xlsx, hardware.kicad_sch]
2025-10-29 lecisz z tym Janek
    [hardware.kicad_sch]
2025-12-13 za Janka
    [esp+peryferia.kicad_sch, espservo.kicad_pcb, espservo.kicad_sch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]
2026-01-04 nowa wersja
    [hardware.kicad_sch, przetwora.kicad_pcb, przetwora.kicad_sch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]
2026-05-13 Add camera functionality
2026-05-19 Figured PIR sensor. Added automatic mode
2026-05-27 Integrated a new sensor
2026-05-27 small rearragmment of raport files
    [BOM.xlsx]
